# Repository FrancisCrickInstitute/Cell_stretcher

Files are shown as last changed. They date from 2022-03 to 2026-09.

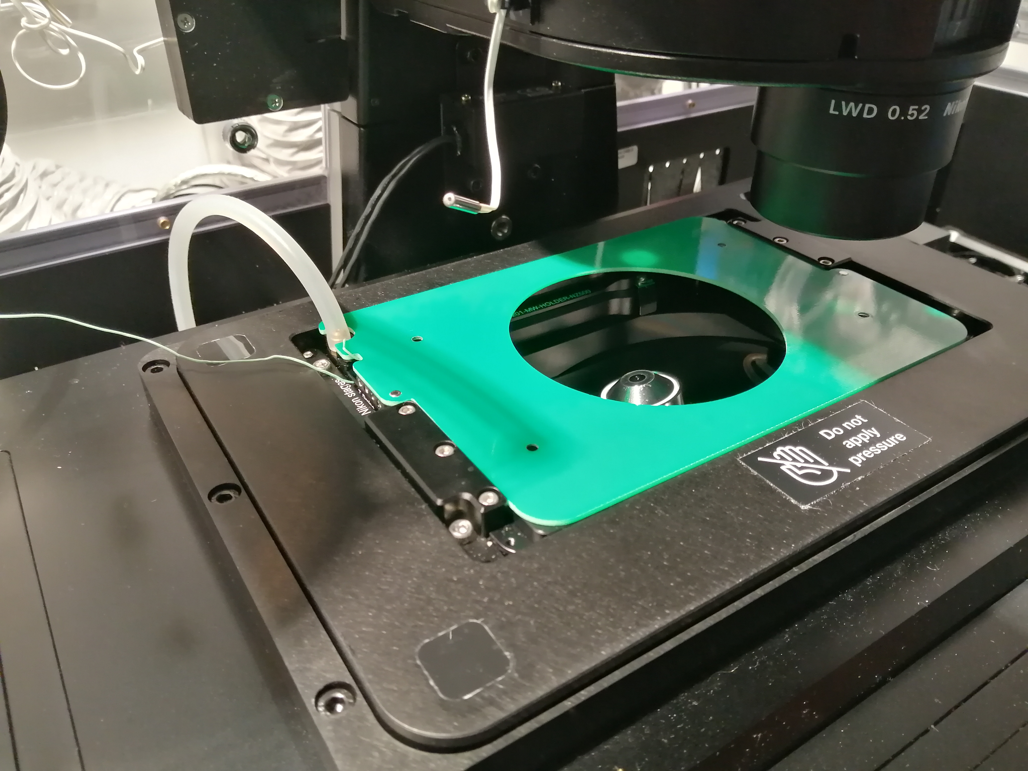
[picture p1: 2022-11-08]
IMG_20221101_121543.jpg

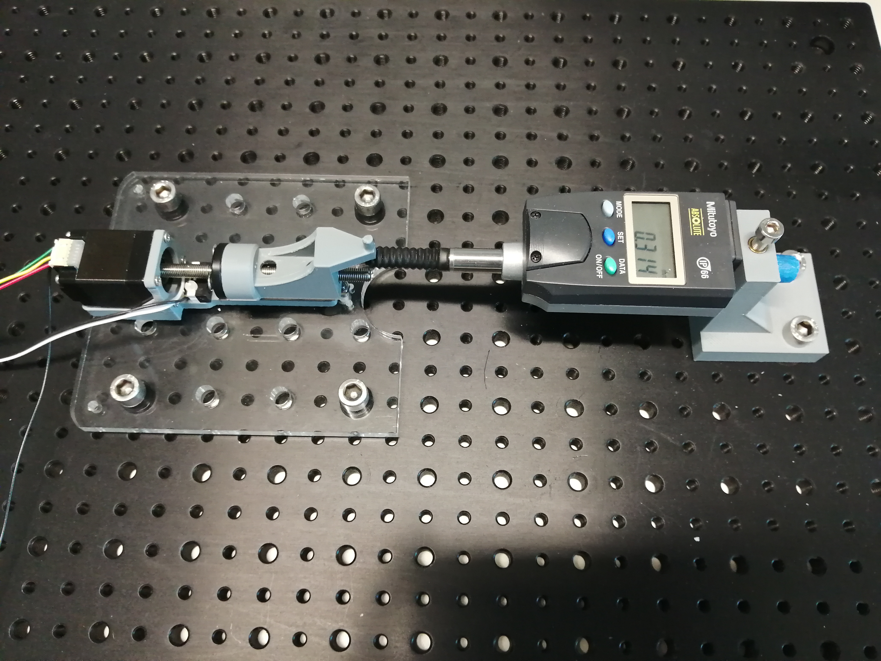
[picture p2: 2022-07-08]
IMG_20220622_173102.jpg

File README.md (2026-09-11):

### Cell sretcher 

Slide1



### Operation

-	Make sure the PDMS insert is not present!!
-	Connect power supply
-	Press ON/OFF button to ON position (| symbol)
-	The device will “home” all the actuators and move them to the centre
-	Load the PDMS insert
-	Select frequency (Hz)
-	Select stretch (mm)
-	Optional - Press stretch button to change mode (alternative, simultaneous…)
-	Press frequency button to start

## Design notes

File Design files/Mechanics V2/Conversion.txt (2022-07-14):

Conversion Report:

Created by DWG TrueView DWG Convert Monday, July 11, 2022, 1:57 PM.

Conversion Summary

------------------

Conversion File Format:  AutoCAD 2004/LT 2004 Drawing Format

Conversion package type: In-place (overwrite files)

Converted DWG files:     4

Recovered DWG files:     0

Conversion errors:       0

Converted Files

---------------

Root Drawings:

	C:\Users\ferrerx\Desktop\Projects\Microscope Calibration pattern\Drawing 1.dwg

	C:\Users\ferrerx\Desktop\Projects\Microscope Calibration pattern\1 circle.dwg

	C:\Users\ferrerx\Desktop\Projects\Microscope Calibration pattern\2 circle big.dwg

	C:\Users\ferrerx\Desktop\Projects\Microscope Calibration pattern\2 circle.dwg

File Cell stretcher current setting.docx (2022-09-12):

Cell stretcher current setting

VREF=8⋅IMAX⋅RCS

Red clone

VREF=8⋅0.6A⋅0.2Ω(Measured) =0.96V

Pololu original

VREF=8⋅0.6A⋅0.068Ω =0.326V

Reference: https://www.pololu.com/product/1182

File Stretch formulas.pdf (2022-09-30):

Stretcℎ (%) =

2 ∗ selected_stretcℎ(mm)
initial diameter(mm)

∗ 100

vel =

selected_stretcℎ(mm)
T
2

= 2

selected_stretcℎ(mm)
T

= 2fselected_stretcℎ(mm)

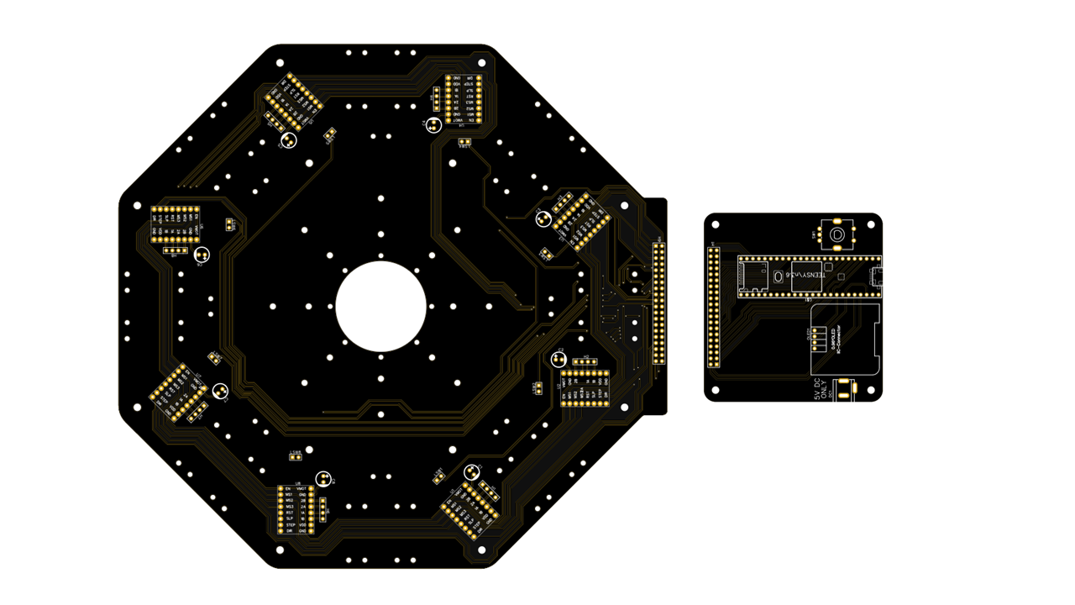
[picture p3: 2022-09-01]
Design files/Electronics/Cell stretcher board.png

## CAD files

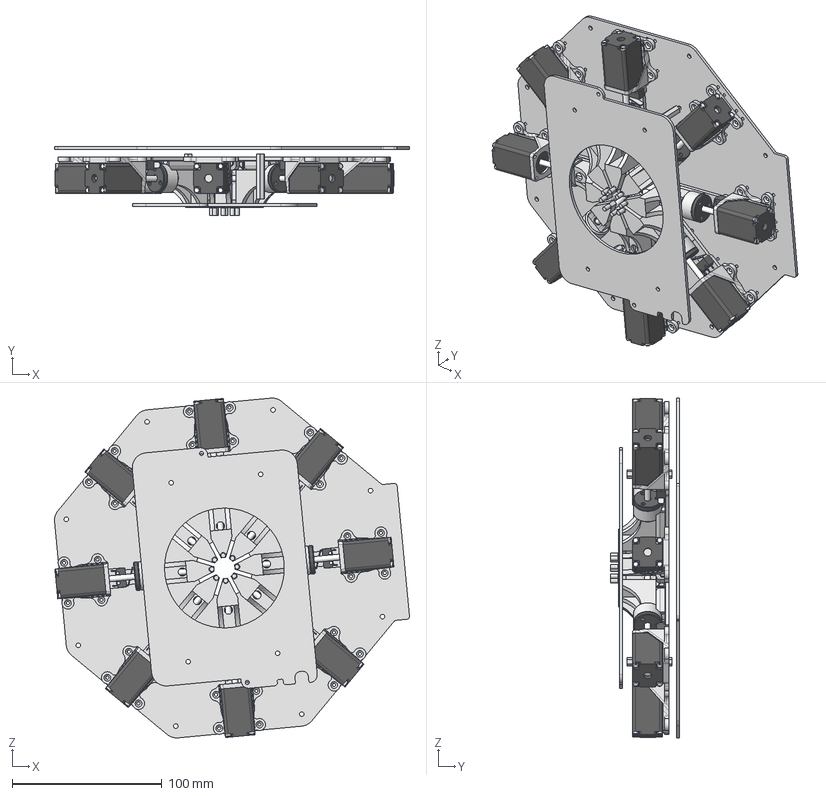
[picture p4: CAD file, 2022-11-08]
Design files/Mechanics/Cell stretcher assembly.stp
237.0 x 46.1 x 226.9 mm
Base
Motor holder x 8
Nema 8 x 8
Microswitch x 8
_BSP1025Rail x 8
_BSP-SL1025 Table x 8
_BSP1015.3 Retainer x 16
Nut x 8
Cart x 8
Microscope lid
Electronics spacer x 2

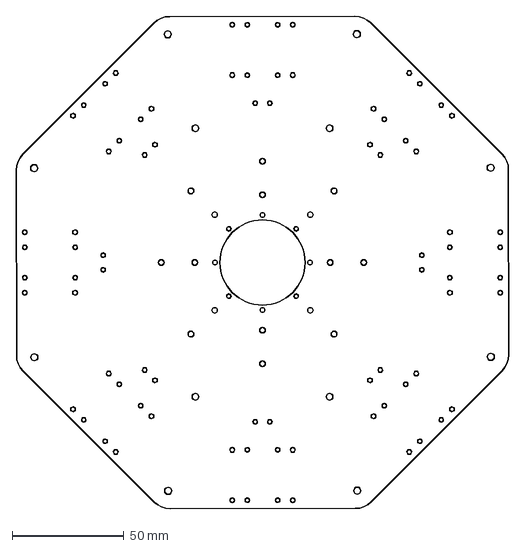
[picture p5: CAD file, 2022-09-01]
Design files/Electronics/Board_outline.dxf
220.1 x 220.1 mm

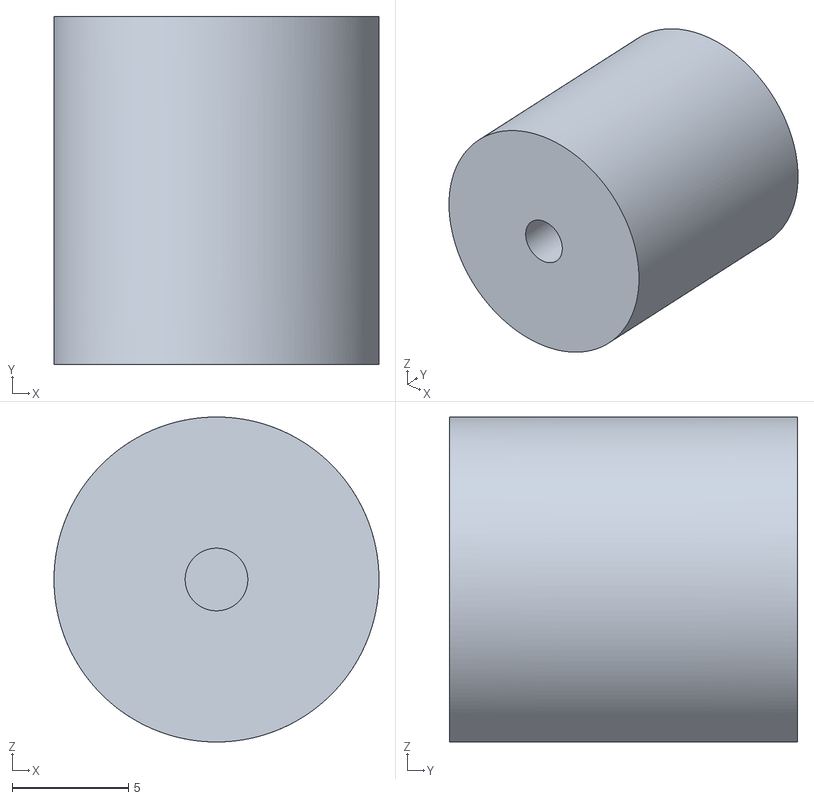
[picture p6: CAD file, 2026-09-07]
Four actuator mould/PDMS stretcher mould divided in parts_2.stl
14.0 x 15.0 x 14.0

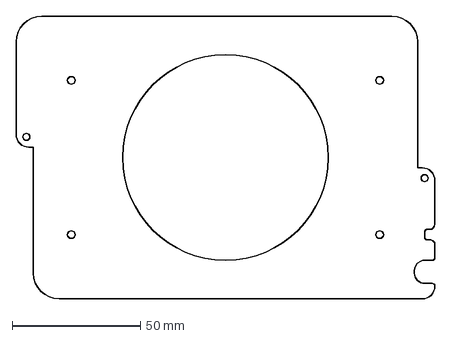
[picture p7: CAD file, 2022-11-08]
Manufacturing files/PCBs/Microscope lid.dxf
163.0 x 110.0 mm

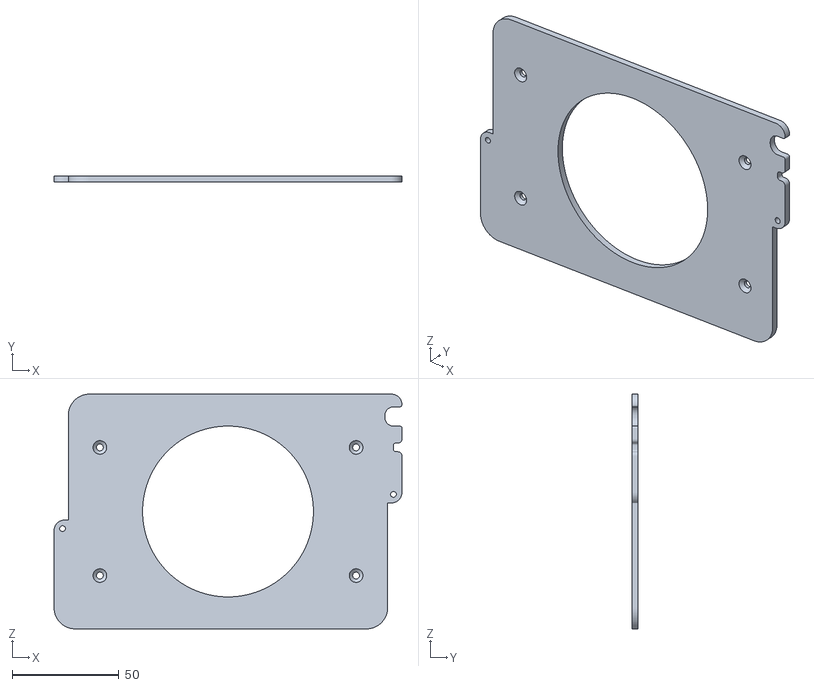
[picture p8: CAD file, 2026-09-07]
Manufacturing files/STL/Microscope lid.stl
163.0 x 3.00 x 110.0

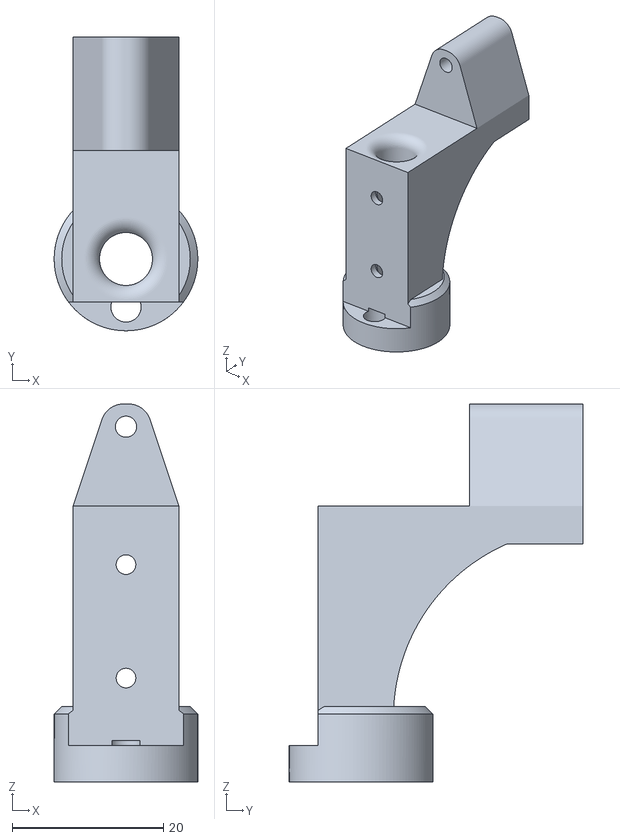
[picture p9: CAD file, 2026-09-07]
Manufacturing files/STL/V2/Cart.stl
19.0 x 38.8 x 50.0

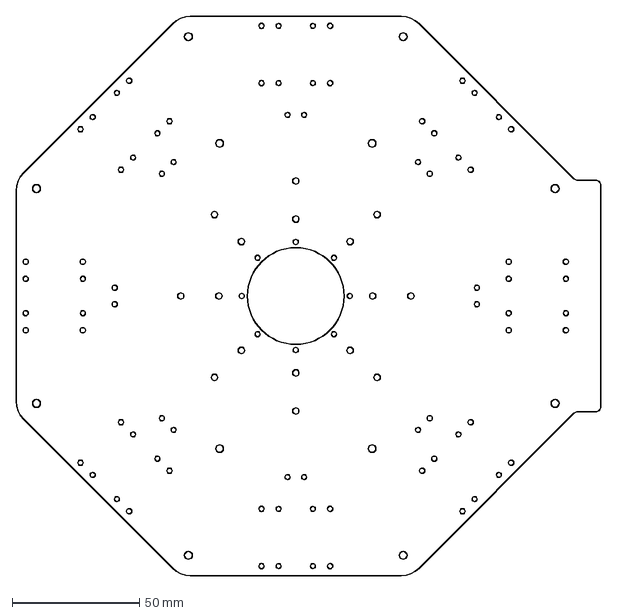
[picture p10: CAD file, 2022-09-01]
Design files/Mechanics/Cell stretcher Board.dxf
230.0 x 220.0 mm

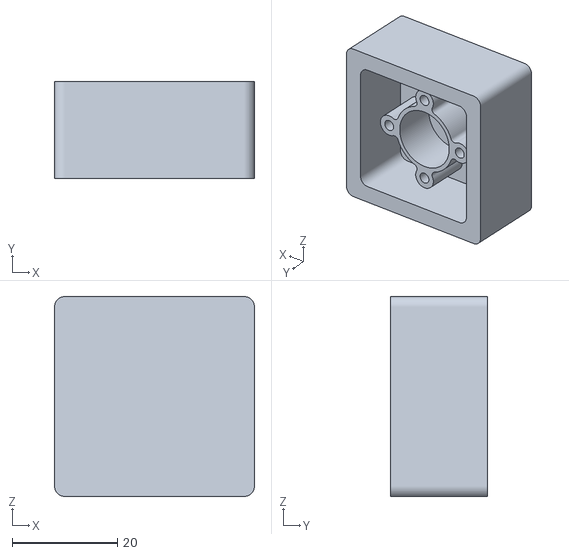
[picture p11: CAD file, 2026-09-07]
Four actuator mould/Ecoflex_mould_through.stl
38.0 x 18.5 x 38.0

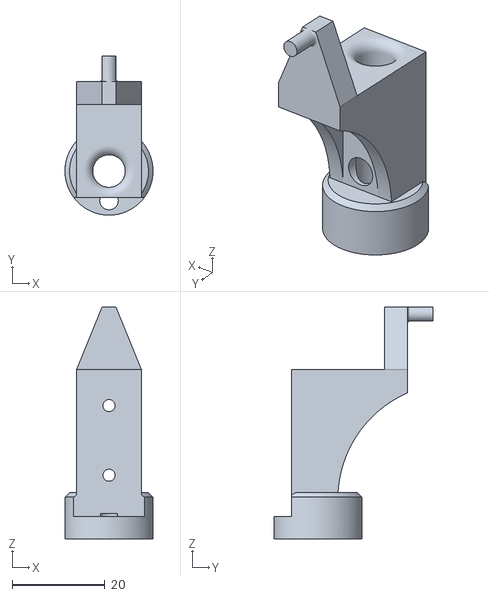
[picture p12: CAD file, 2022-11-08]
Manufacturing files/STL/Cart.stl
19.0 x 34.3 x 50.0

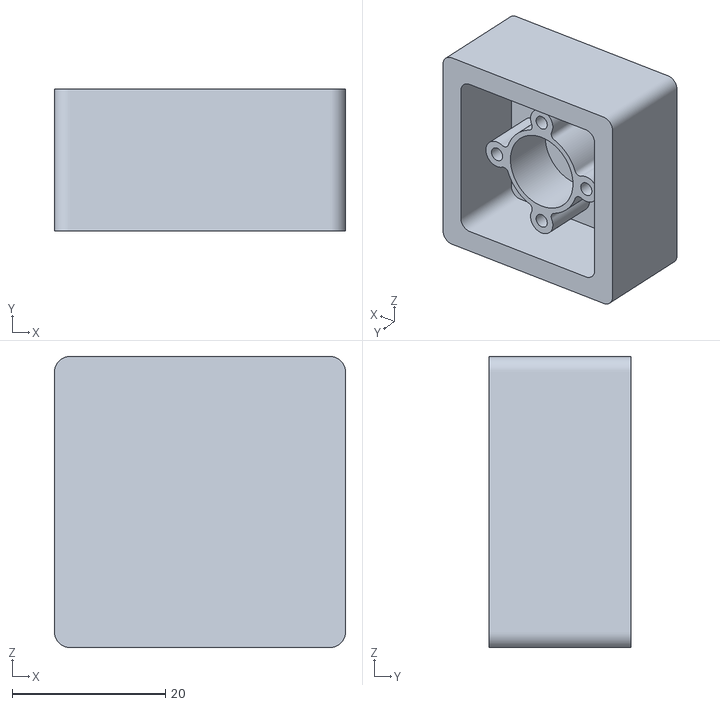
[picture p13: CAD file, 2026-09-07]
Four actuator mould/Ecoflex_mould.stl
38.0 x 18.5 x 38.0

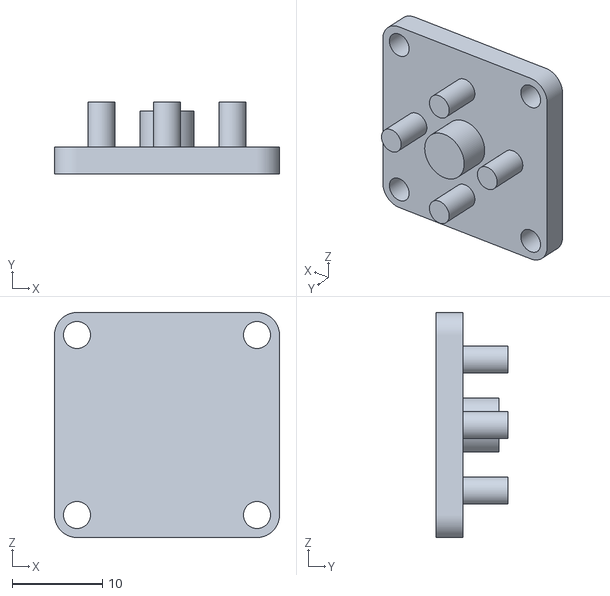
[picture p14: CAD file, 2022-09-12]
Four actuator mould/Manufacturing files/PDMS stretcher mould A (x4).stl
25.0 x 8.00 x 25.0

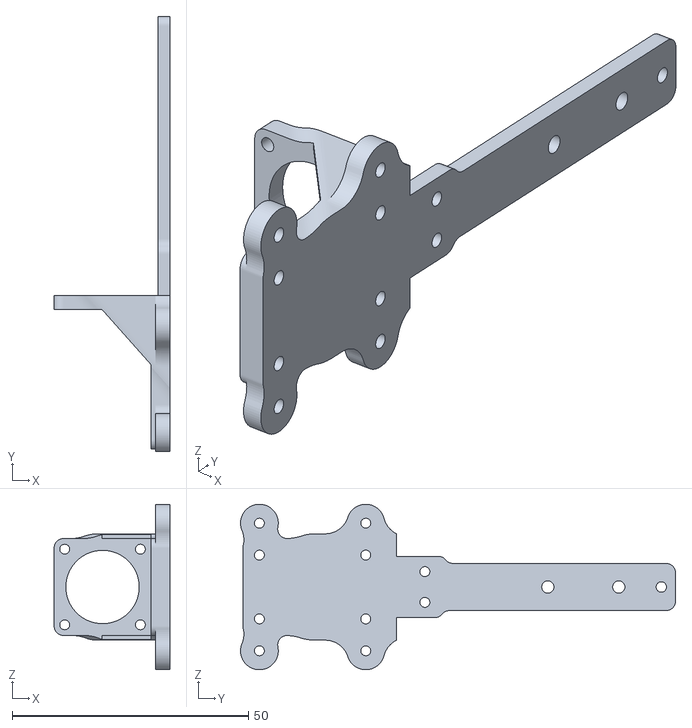
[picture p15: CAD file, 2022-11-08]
Manufacturing files/STL/Motor holder.stl
24.5 x 92.0 x 35.0

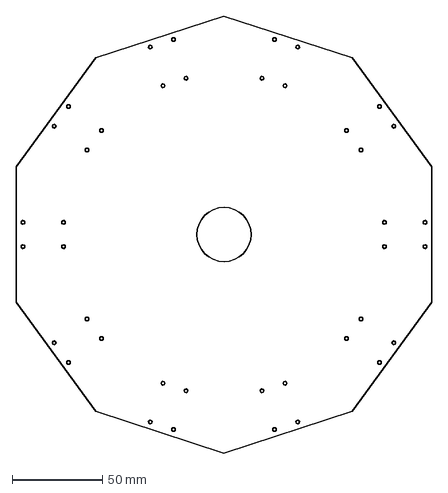
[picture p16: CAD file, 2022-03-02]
Design files/Mechanics/Base.dxf
230.0 x 241.8 mm

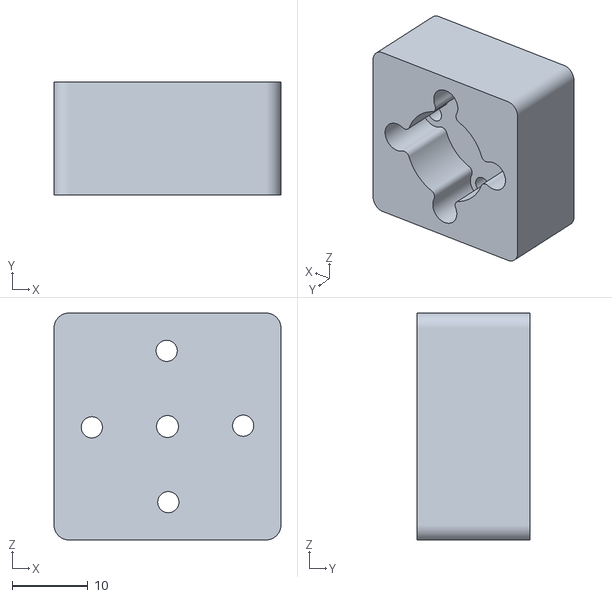
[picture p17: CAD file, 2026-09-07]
Four actuator mould/PDMS stretcher mould divided in parts.stl
30.0 x 15.0 x 30.0

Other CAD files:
Four actuator mould/Manufacturing files/Stretcher top mould x4.dwg
Four actuator mould/Manufacturing files/Stretcher intermediate mould x4.dwg
Design files/Mechanics/Top.dwg
Design files/Mechanics/BSP10-25.stp
Design files/Mechanics V2/BSP10-25 bottom.iam
Design files/Mechanics V2/BSP10-25 top.iam
Design files/Mechanics V2/BSP10-35 Top.iam
Design files/Mechanics V2/BSP10-35 bottom.iam
Design files/Mechanics V2/Base.ipt
Design files/Mechanics V2/Cart.ipt
Design files/Mechanics V2/Cell stretcher assembly.iam
Design files/Mechanics V2/Clamp.ipt
Design files/Mechanics V2/Coupler.ipt
Design files/Mechanics V2/Electronics spacer.ipt
Design files/Mechanics V2/Limit switch.ipt
Design files/Mechanics V2/Linear actuator.iam
Design files/Mechanics V2/M4 nut.ipt
Design files/Mechanics V2/M4 threaded bar.ipt
Design files/Mechanics V2/Microscope lid.ipt
Design files/Mechanics V2/Motor holder.ipt
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

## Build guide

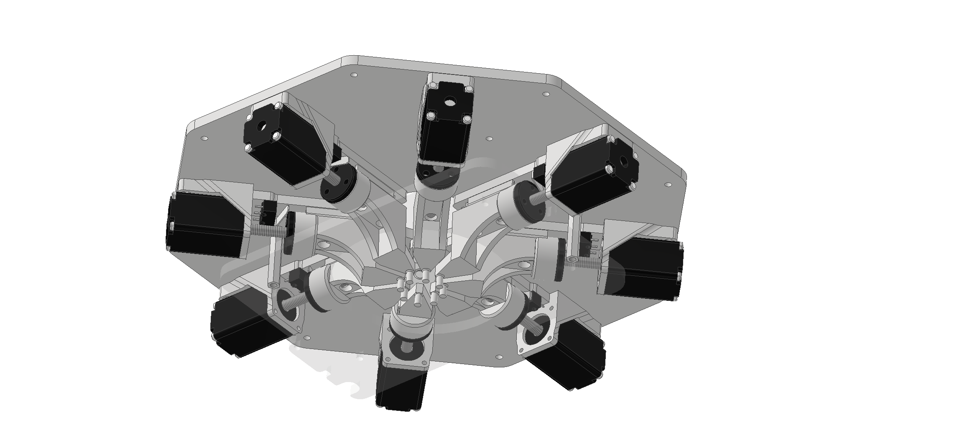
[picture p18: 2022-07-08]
Cell stretcher assembly.png

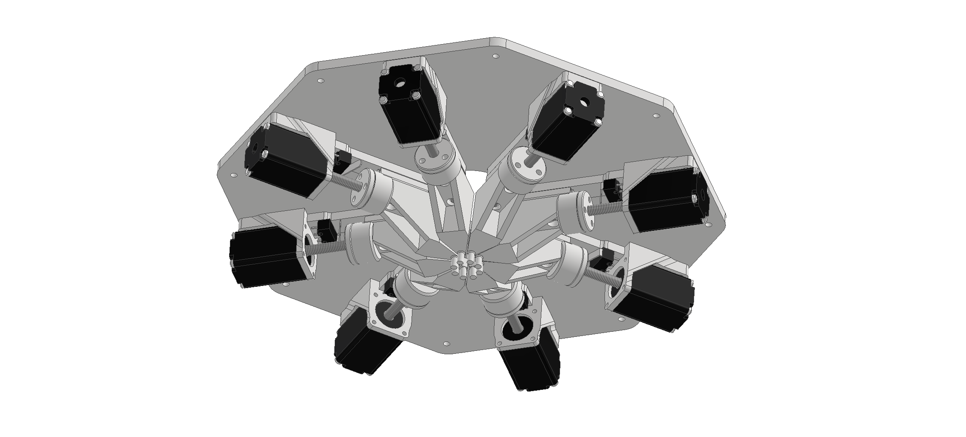
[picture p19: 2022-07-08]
Design files/Mechanics/Cell stretcher assembly.png

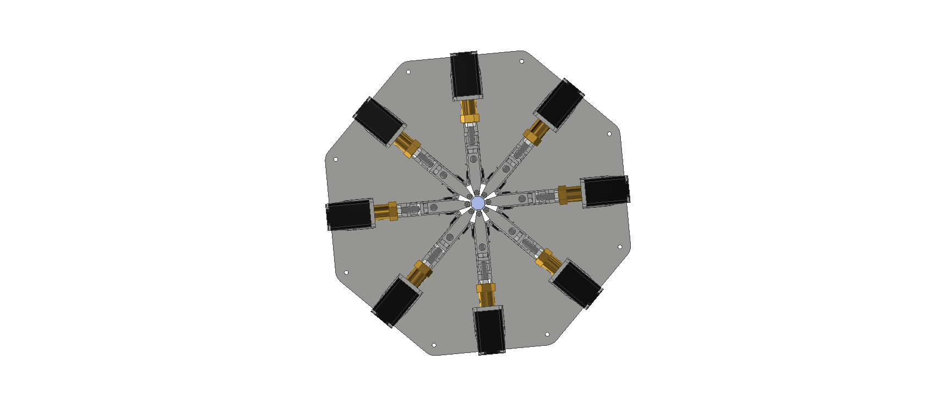
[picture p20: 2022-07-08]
Design files/Mechanics/Cell stretcher assembly top.png

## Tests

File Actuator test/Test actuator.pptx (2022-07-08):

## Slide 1

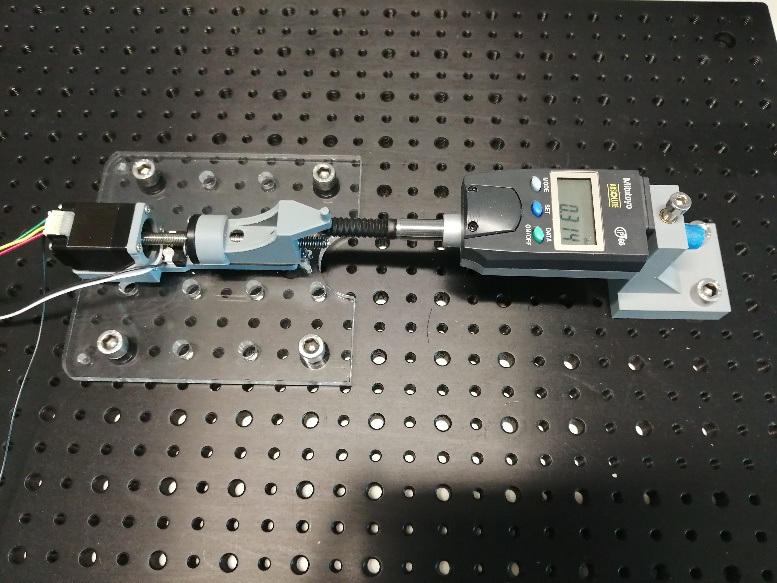
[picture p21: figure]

Resolution of 1.587 um ≈ 1.6 um

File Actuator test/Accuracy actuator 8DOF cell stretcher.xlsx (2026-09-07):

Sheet: Sheet3
Steps | um
0 | 2
10 | 17 | 15 | Average | 15.88461538
20 | 33 | 16
30 | 48 | 15
40 | 64 | 16
50 | 80 | 16
60 | 95 | 15
70 | 111 | 16
80 | 127 | 16
90 | 142 | 15
100 | 159 | 17
110 | 174 | 15
120 | 190 | 16
130 | 206 | 16
140 | 222 | 16
150 | 238 | 16
160 | 255 | 17
170 | 271 | 16
180 | 287 | 16
190 | 303 | 16
200 | 319 | 16
210 | 335 | 16
220 | 351 | 16
230 | 367 | 16
240 | 383 | 16
250 | 399 | 16
260 | 415 | 16

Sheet: Sheet2
1 revolution distance (400 steps)
1 |  | 2 |  | 3 |  | 4 |  | 5 |  | 6 |  | 7 |  | 8 |  | 9 |  | 10
316 | 0 | 318 | 0 | 315 | 0 | 315 | 0 | 314 | 0 | 314 | 0 | 314 | 0 | 312 | 0 | 313 | 0 | 313 | 0
941 | 625 | 945 | 627 | 943 | 628 | 943 | 628 | 945 | 631 | 945 | 631 | 945 | 631 | 943 | 631 | 944 | 631 | 945 | 632
1574 | 633 | 1578 | 633 | 1579 | 636 | 1578 | 635 | 1580 | 635 | 1580 | 635 | 1580 | 635 | 1579 | 636 | 1579 | 635 | 1580 | 635
2209 | 635 | 2213 | 635 | 2214 | 635 | 2214 | 636 | 2215 | 635 | 2215 | 635 | 2216 | 636 | 2214 | 635 | 2215 | 636 | 2215 | 635
 |  | 1 |  | 2 |  | 3 |  | 4 |  | 5 |  | 6 |  | 7 |  | 8 |  | 9 |  | 10
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

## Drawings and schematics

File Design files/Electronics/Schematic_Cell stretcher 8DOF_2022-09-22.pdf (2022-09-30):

## Servo motor drivers

## Homing limit switches

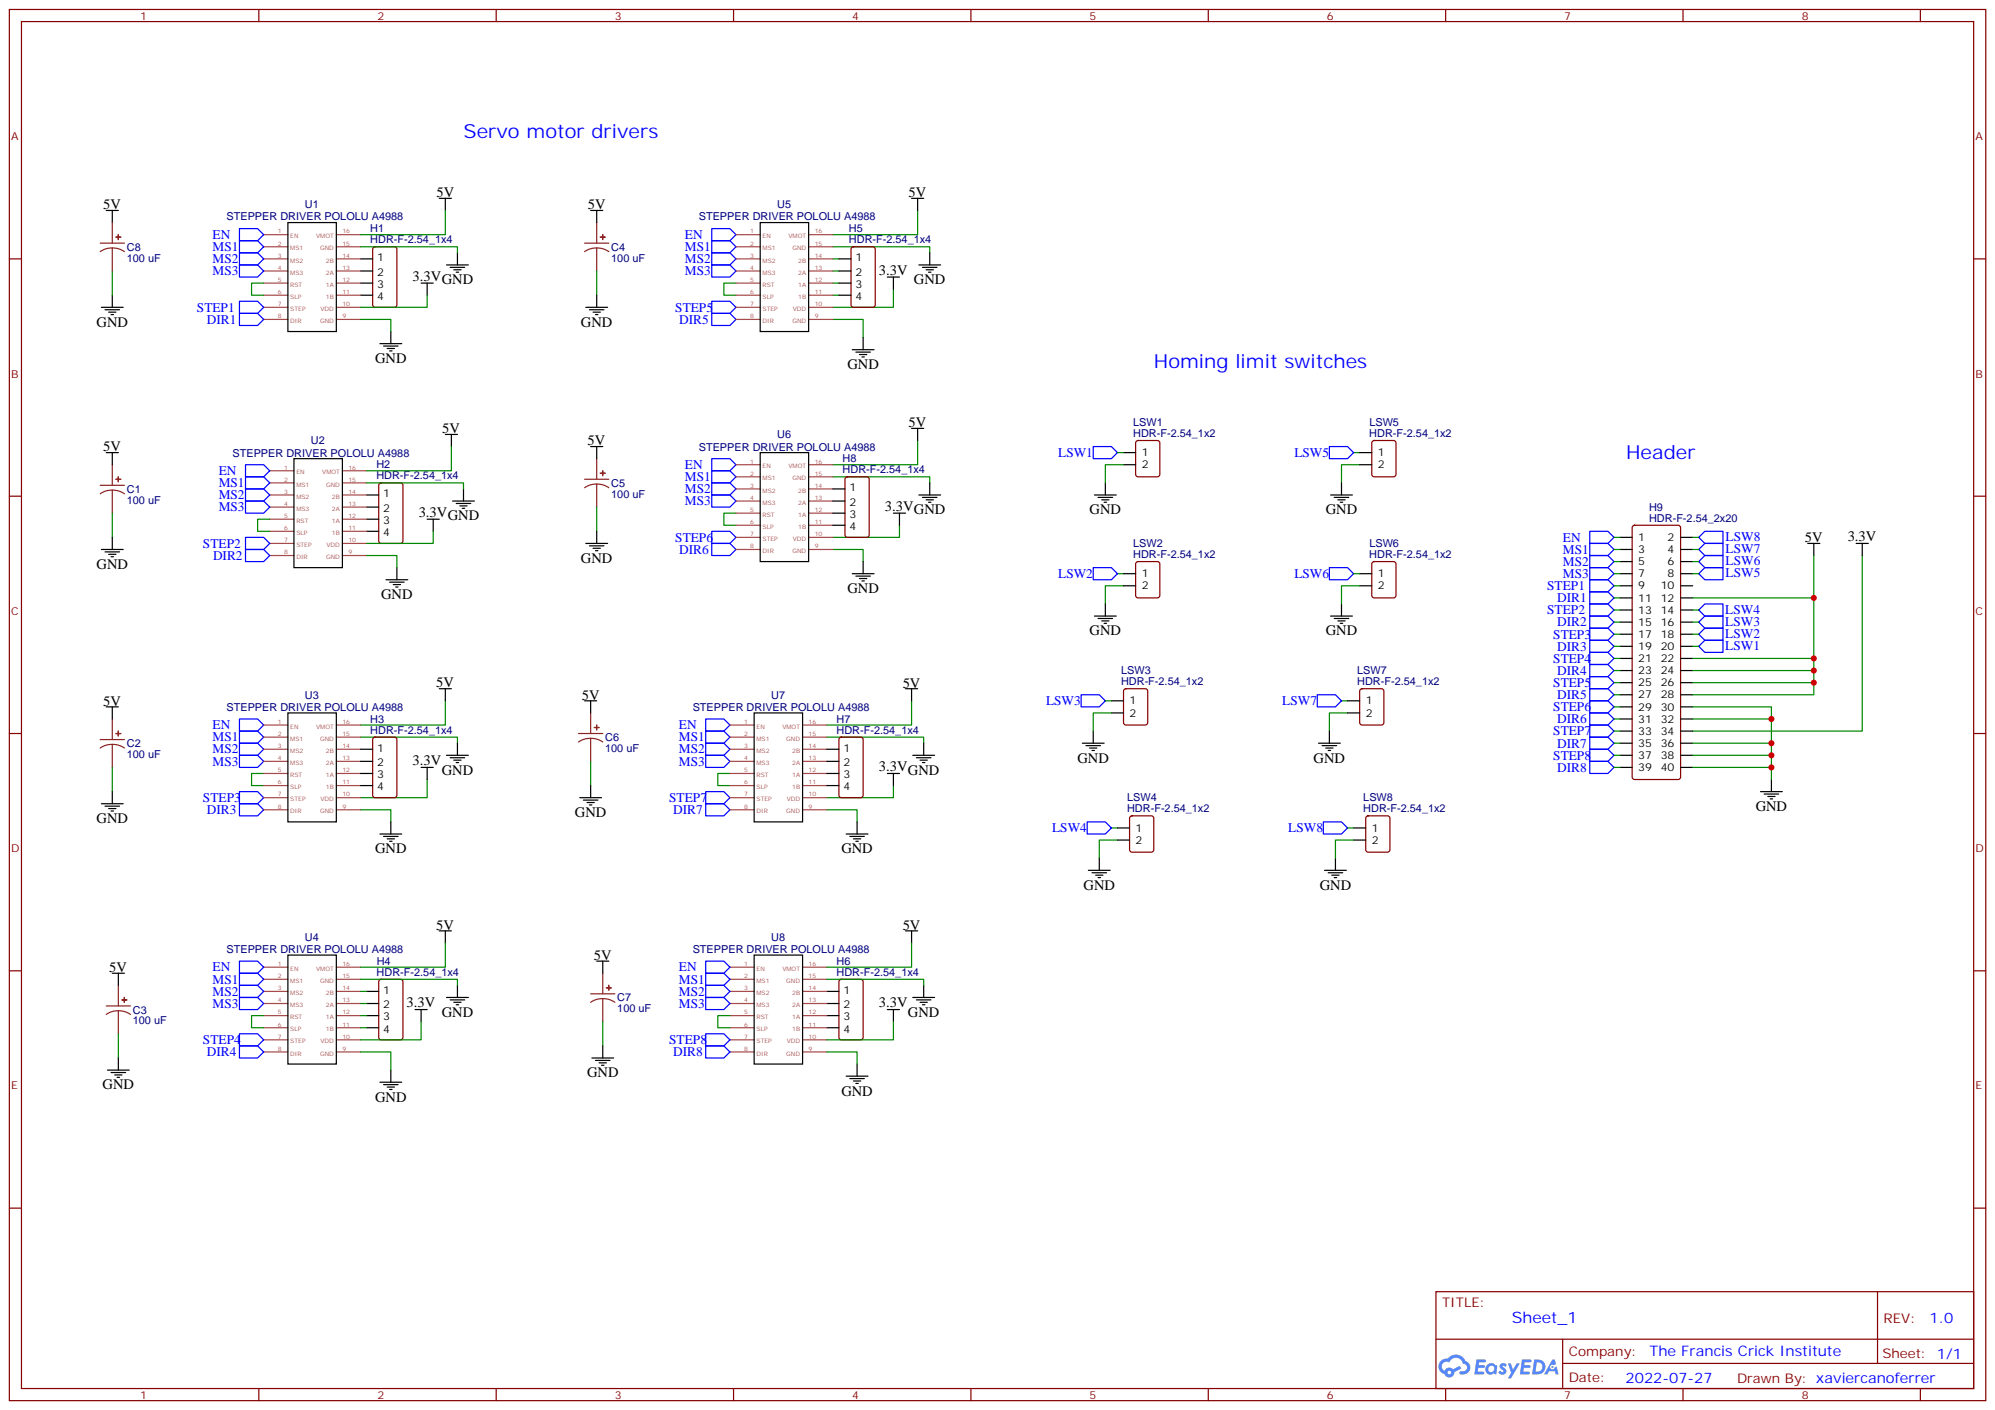
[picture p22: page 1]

Company: The Francis Crick Institute

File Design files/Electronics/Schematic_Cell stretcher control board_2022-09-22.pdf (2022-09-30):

## Teensy 3.5 Power

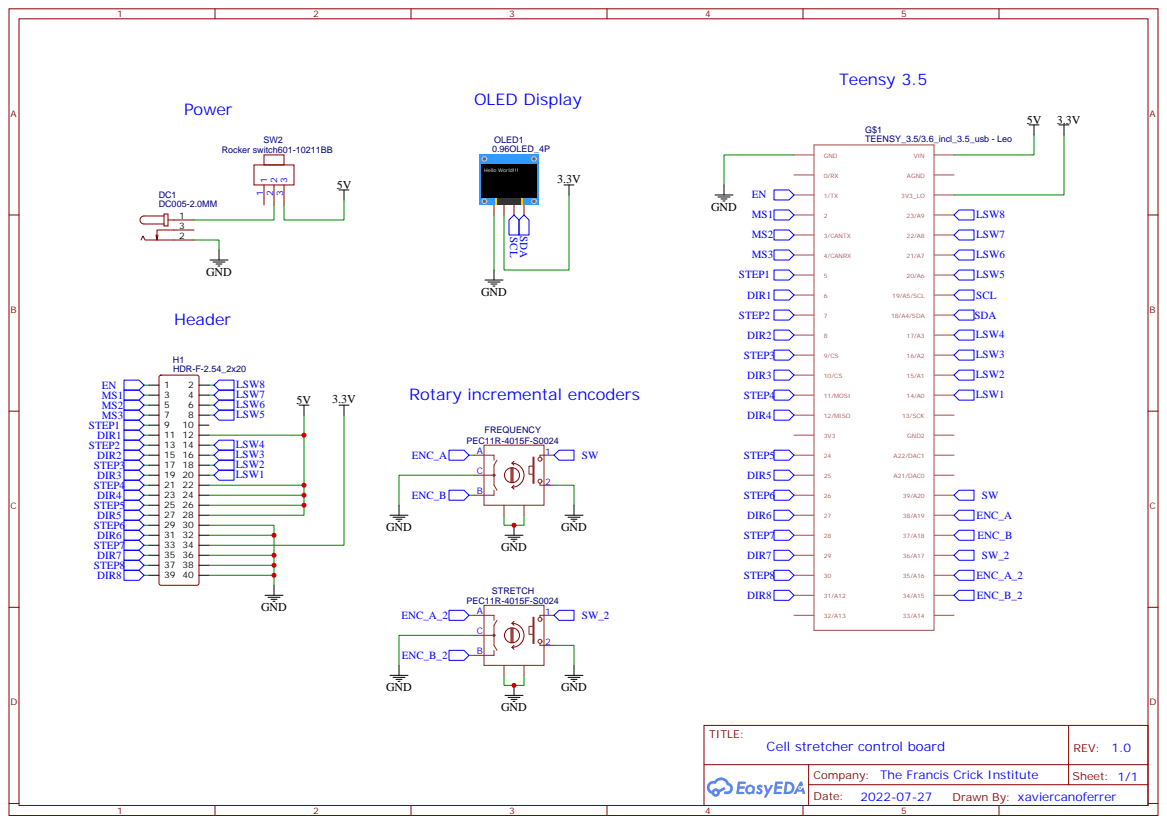
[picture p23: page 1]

Company: The Francis Crick Institute

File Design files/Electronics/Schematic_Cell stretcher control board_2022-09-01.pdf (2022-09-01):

## Teensy 3.5 Power

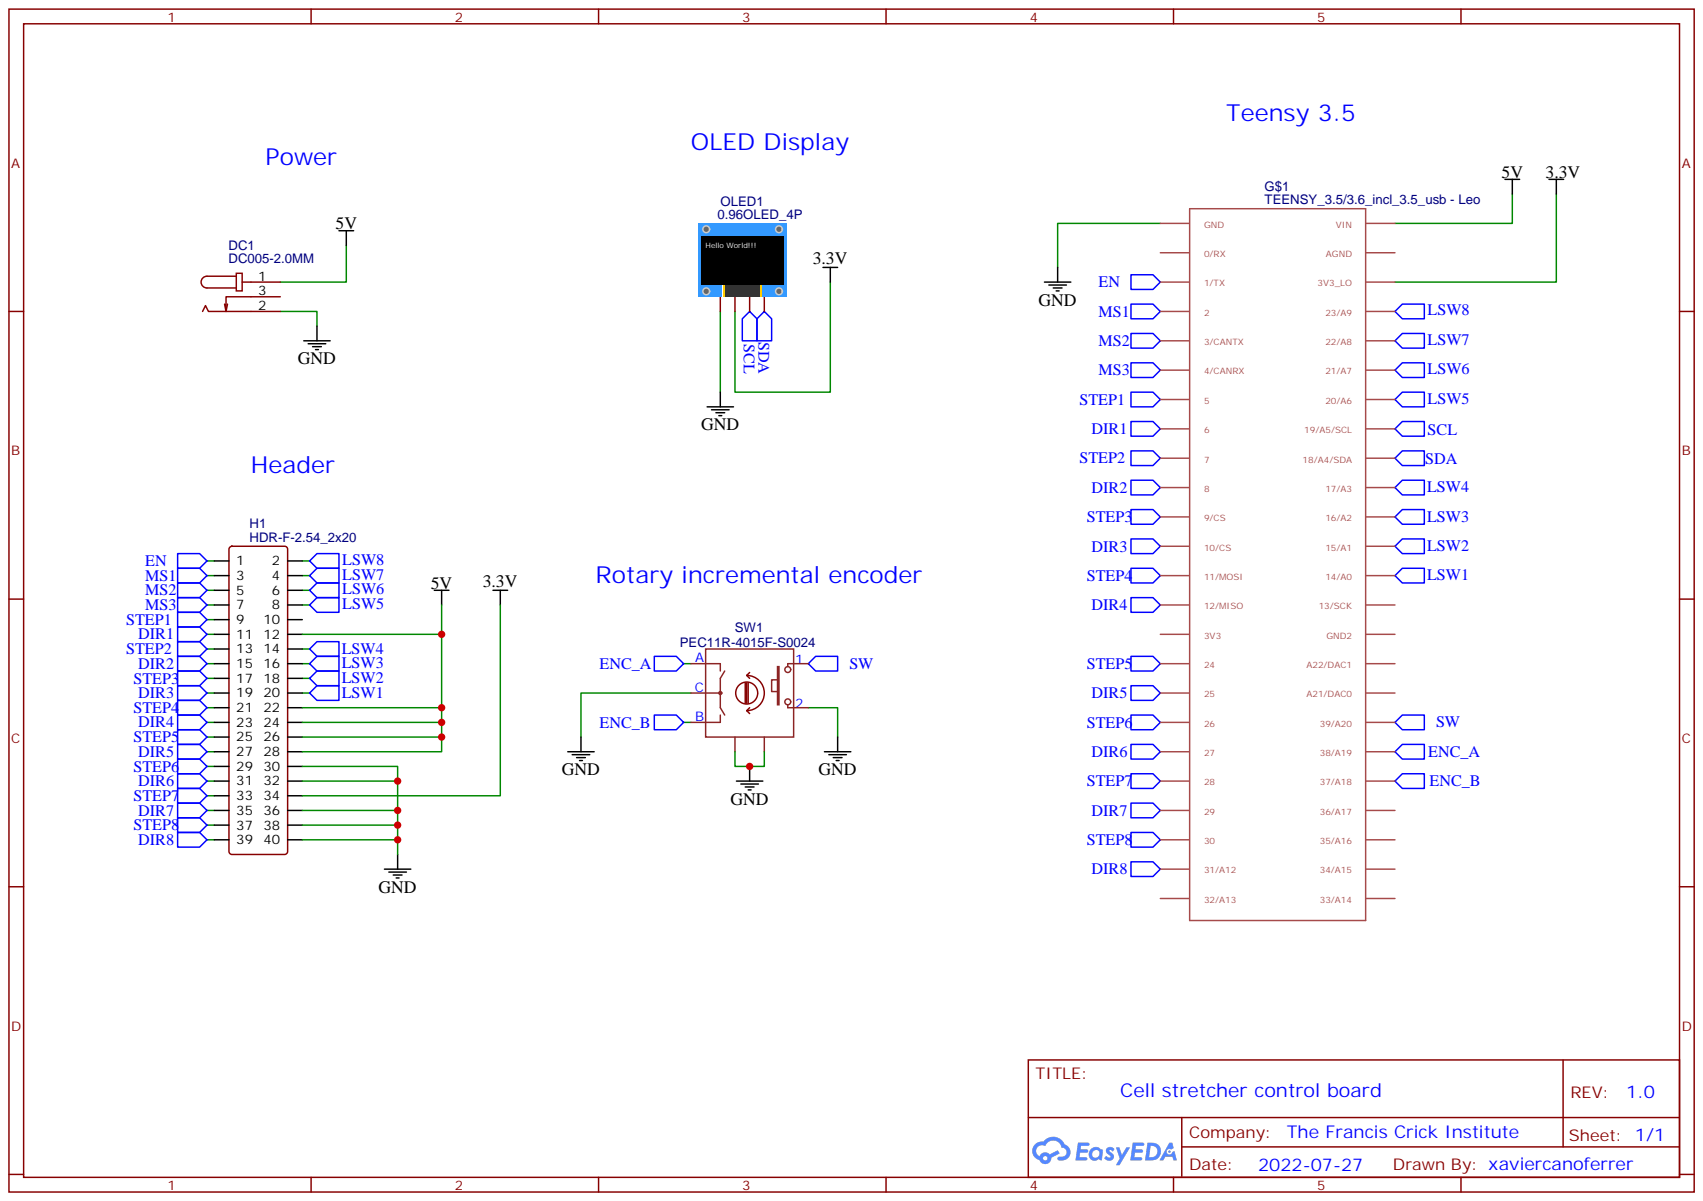
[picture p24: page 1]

Company: The Francis Crick Institute

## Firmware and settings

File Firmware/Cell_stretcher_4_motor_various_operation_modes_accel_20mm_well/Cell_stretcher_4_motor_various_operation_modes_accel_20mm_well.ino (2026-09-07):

#include "TeensyStep.h"
#include <Encoder.h>
#include <Wire.h>
#include <Adafruit_GFX.h>
#include <Adafruit_SSD1306.h>
#include <Bounce.h>

Encoder freq_knob(38, 37);
Encoder stretch_knob(35, 34);


const int encoder_SW = 39;
const int encoder_SW_2 = 36;

// Instantiate a Bounce object with a 5 millisecond debounce time
Bounce pushbutton = Bounce( encoder_SW,20 ); 
Bounce pushbutton2 = Bounce( encoder_SW_2,20 ); 

const int Enable = 1;

Stepper M1(7, 8);       // STEP pin: 7, DIR pin: 6  // The stepper class encapsulates the physical properties of a stepper motor like pin numbers of the STEP and DIR signals, speed and acceleration of the motor.
Stepper M2(11, 12);
Stepper M3(26, 27);
Stepper M4(30, 31);

const int SW1 = 15;
const int SW2 = 17;
const int SW3 = 21;
const int SW4 = 23;

StepControl step_controller;    // The StepControl class is used to synchronously move up to 10 motors to their target positions.

#define SCREEN_WIDTH 128 // OLED display width, in pixels
#define SCREEN_HEIGHT 64 // OLED display height, in pixels

// Declaration for an SSD1306 display connected to I2C (SDA, SCL pins)
#define OLED_RESET     -1 // Reset pin # (or -1 if sharing Arduino reset pin)

Adafruit_SSD1306 display(SCREEN_WIDTH, SCREEN_HEIGHT, &Wire, OLED_RESET);

const int MS1 = 2;
const int MS2 = 3;
const int MS3 = 4;

float um_per_step = 1.6; //400 steps/revolution
int steps = 0;
const int initial_steps = 3000-1080;//3000;
const int compression_steps = 3000;

int mode = 0;

float freq = 0;
float freq_factor = 0.05;
float stretch = 0;
float T;
const float initial_stretch_diameter = 20;
float p_stretch;
unsigned long t = 0;
bool state = 0;
float vel;
int steps_s;
float accel;
int steps_s2;

void setup()
{
  pinMode(MS1, OUTPUT);    // set the MS1, MS2, MS3 and Enable as an outputs
  pinMode(MS2, OUTPUT);
  pinMode(MS3, OUTPUT);

  pinMode(Enable, OUTPUT);

  digitalWrite(MS1, HIGH); // sets the digital pin MS1, MS2, MS3 to HIGH
  digitalWrite(MS2, LOW);
  digitalWrite(MS3, LOW);

  digitalWrite(Enable, LOW); // set the enables to LOW

  // Set the motor max acceleration
  M1.setMaxSpeed(1000)
  .setAcceleration(5000)   // stp/s^2
  .setInverseRotation(true);

  M2.setMaxSpeed(1000)
  .setAcceleration(5000)   // stp/s^2
  .setInverseRotation(true);

  M3.setMaxSpeed(1000)
  .setAcceleration(5000)   // stp/s^2
  .setInverseRotation(true);

  M4.setMaxSpeed(1000)
  .setAcceleration(5000)   // stp/s^2
  .setInverseRotation(true);

  pinMode(SW1, INPUT_PULLUP);
  pinMode(SW2, INPUT_PULLUP);
  pinMode(SW3, INPUT_PULLUP);
  pinMode(SW4, INPUT_PULLUP);
  
  pinMode(encoder_SW, INPUT_PULLUP);
  pinMode(encoder_SW_2, INPUT_PULLUP);
  
  Serial.begin(115200);

  display.begin(SSD1306_SWITCHCAPVCC, 0x3C);

  delay(1000);
  display.clearDisplay(); 

  Homing_routine();

  // Go to initial position
  M1.setTargetAbs(initial_steps);
  M2.setTargetAbs(initial_steps);
  M3.setTargetAbs(initial_steps);
  M4.setTargetAbs(initial_steps);
  step_controller.move(M1, M2, M3, M4);

  
  digitalWrite(Enable, HIGH); // Remove power from the motor to decrease heat
}

void loop()
{

  freq = abs(freq_knob.read())/4*freq_factor; // Select the frequency in Hz
  stretch = abs(stretch_knob.read())/4*0.05; // select the stretch in mm 

  //Constrained frequancy and stretch
  freq = constrain(freq, 0, 4);
  stretch = constrain(stretch, 0, 2);
  
  // Calculate percentage of stretch, period and motor speed based on the previous user selection
  p_stretch = 2*stretch/(initial_stretch_diameter)*100; //2 times because it is in 2 directions simultaneously
  T = 1/freq; // Calculate the period
  
  vel = 1.5*(stretch/(T/2)); // 1.5 = 3/2 Because 1/3 of the time is used for accelerating, 1/3 is used for constant velocity, and 1/3 is used for decelerating.
  accel = vel/(T/6);
  
  //t = T*1000; // Convert the period in milliseconds

  // Get steps from mm selected by the user using the stretch knob
  steps = mm_to_step(stretch/2); // Divided by two beacuse it is what will move each arm

  // Get steps/s from the selected velocity
  steps_s = mm_to_step(vel);

  // Get steps/s^2 from the acceleration calculated based on displacement and frequency
  steps_s2 = mm_to_step(accel);
  
  //Set the selected motor speed
  set_velocity(steps_s);

  //Set the acceleration
  set_acceleration(steps_s2);

  OLED_display(); // Display selection

  read_pushbutton();
  read_pushbutton2();

  if (state == 1 && mode == 0)
  {
    read_pushbutton();
    simultaneous();  
  }

  if (state == 1 && mode == 1)
  {
    read_pushbutton();
    alternate();  
  }
  if (state == 1 && mode == 2)
  {
    read_pushbutton();
    one_by_one();
  };
  if (state == 1 && mode == 3)
  {
    read_pushbutton();
    x_axis();
  };
  if (state == 1 && mode == 4)
  {
    read_pushbutton();
    y_axis();
  };
  if (state == 1 && mode == 5)
  {
    read_pushbutton();
    compression();
  };
}

// Function to get the steps from the mm
int mm_to_step (float mm)
{
  int steps;
  steps = mm * 1600; // 1600 steps per mm
  return steps;
}

// Function to get the mm from the steps
float step_to_mm (int steps)
{
  float mm;
  mm = steps * 0.001600; // 1.587 um per step
  return mm;
}

//Function to rotate the left motor CW
void TurnClockwise_M1 (int pd)
{
  digitalWrite(8, 1);
  digitalWrite(7, HIGH);
  digitalWrite(7, LOW);
  delayMicroseconds(pd);
}

//Function to rotate the right motor CW
void TurnClockwise_M2 (int pd)
{
  digitalWrite(12, 1);
  digitalWrite(11, HIGH);
  digitalWrite(11, LOW);
  delayMicroseconds(pd);
}

void TurnClockwise_M3 (int pd)
{
  digitalWrite(27, 1);
  digitalWrite(26, HIGH);
  digitalWrite(26, LOW);
  delayMicroseconds(pd);
}

void TurnClockwise_M4 (int pd)
{
  digitalWrite(31, 1);
  digitalWrite(30, HIGH);
  digitalWrite(30, LOW);
  delayMicroseconds(pd);
}


void read_pushbutton()
{
  if (pushbutton.update())
  {
    if (pushbutton.fallingEdge())
    {
      state = !state;
    }
  }
}

void read_pushbutton2()
{
  if (pushbutton2.update())
  {
    if (pushbutton2.fallingEdge())
    {
      mode = mode +1;
      mode = constrain(mode, 0, 5);
    }
  }
}

void Homing_routine()
{
  
  while (digitalRead(SW1) == HIGH)
  {
    TurnClockwise_M1 (1000);
    Serial.println(digitalRead(SW1));
  }

  while (digitalRead(SW2) == HIGH)
  {
    TurnClockwise_M2 (1000);
    Serial.println(digitalRead(SW2));
  }

  while (digitalRead(SW3) == HIGH)
  {
    TurnClockwise_M3 (1000);
    Serial.println(digitalRead(SW3));
  }

  while (digitalRead(SW4) == HIGH)
  {
    TurnClockwise_M4 (1000);
    Serial.println(digitalRead(SW4));
  }
}

void set_velocity(int v)
{  
  // Set the motor max speed
  M1.setMaxSpeed(v);
  M2.setMaxSpeed(v);
  M3.setMaxSpeed(v);
  M4.setMaxSpeed(v);
}

void set_acceleration(int a)
{  
  // Set the motor max speed
  M1.setAcceleration(a);
  M2.setAcceleration(a);
  M3.setAcceleration(a);
  M4.setAcceleration(a);
}
void OLED_display()
{
  display.clearDisplay();
  display.setTextColor(WHITE);        // Draw white text
  display.setCursor(0, 0);
  display.setTextSize(1);
  display.println(F("8 DOF cell stretcher"));
  display.println();
  display.print(F("Frequency:"));
  display.print(freq);
  display.println(F(" Hz"));
  //display.println();
  display.print(F("Stretch:"));
  display.print(stretch);
  display.println(F(" mm"));
  //display.println();
  display.print(F("%Stretch:"));
  display.print(p_stretch);
  display.println(F(" %"));
//  display.print(F("Steps stretch:"));
//  display.println(steps);
  //display.println();
  display.print(F("Period:"));
  display.print(T);
  display.println(F(" s"));
  //display.println();
  display.print(F("State:"));
  //display.print(state);
  if (state == 0){display.println(F("Inactive"));}
  if (state == 1){display.println(F("Active"));}
  display.print(F("Mode:"));
  if (mode == 0){display.println(F("Simult"));}
  if (mode == 1){display.println(F("Alternate"));}
  if (mode == 2){display.println(F("Separete"));}
  if (mode == 3){display.println(F("X axis"));}
  if (mode == 4){display.println(F("Y axis"));}
  if (mode == 5){display.println(F("Compress"));}
  display.print(mode);
  display.display();
}

void simultaneous()
{
   digitalWrite(Enable, LOW); // Enable the motor again
    
    // Set the target for each motor and move to the target
    M1.setTargetAbs(initial_steps-steps);
    M2.setTargetAbs(initial_steps-steps);
    M3.setTargetAbs(initial_steps-steps);
    M4.setTargetAbs(initial_steps-steps);
    step_controller.move(M1, M2, M3, M4);

    digitalWrite(Enable, HIGH); // Remove power from the motor to decrease heat

    //delay(t);

    digitalWrite(Enable, LOW); // Enable the motor again

    // Com back to the origin
    M1.setTargetAbs(initial_steps);
    M2.setTargetAbs(initial_steps);
    M3.setTargetAbs(initial_steps);
    M4.setTargetAbs(initial_steps);
    step_controller.move(M1, M2, M3, M4);

    digitalWrite(Enable, HIGH); // Remove power from the motor to decrease heat  
}


void compression()
{
   digitalWrite(Enable, LOW); // Enable the motor again
    
    // Set the target for each motor and move to the target
    M1.setTargetAbs(initial_steps-steps);
    M2.setTargetAbs(initial_steps-steps);
    M3.setTargetAbs(initial_steps-steps);
    M4.setTargetAbs(initial_steps-steps);
    step_controller.move(M1, M2, M3, M4);

    digitalWrite(Enable, HIGH); // Remove power from the motor to decrease heat

    //delay(t);

    digitalWrite(Enable, LOW); // Enable the motor again

    // Com back to the origin but 2 mm closer
    M1.setTargetAbs(compression_steps);
    M2.setTargetAbs(compression_steps);
    M3.setTargetAbs(compression_steps);
    M4.setTargetAbs(compression_steps);
    step_controller.move(M1, M2, M3, M4);

    digitalWrite(Enable, HIGH); // Remove power from the motor to decrease heat  
}

void alternate()
{
    
    digitalWrite(Enable, LOW); // Enable the motor again
    
    // Move x axis
    M1.setTargetAbs(initial_steps-steps);
    M3.setTargetAbs(initial_steps-steps);
    step_controller.move(M1, M3);

    digitalWrite(Enable, HIGH); // Remove power from the motor to decrease heat

    //delay(t);

    digitalWrite(Enable, LOW); // Enable the motor again

    // Com back to the origin
    M1.setTargetAbs(initial_steps);
    M3.setTargetAbs(initial_steps);
    step_controller.move(M1, M3);

    digitalWrite(Enable, HIGH); // Remove power from the motor to decrease heat  

    digitalWrite(Enable, LOW); // Enable the motor again

    // Move y axis
    M2.setTargetAbs(initial_steps-steps);
    M4.setTargetAbs(initial_steps-steps);
    step_controller.move(M2, M4);

    digitalWrite(Enable, HIGH); // Remove power from the motor to decrease heat

    //delay(t);

    digitalWrite(Enable, LOW); // Enable the motor again

    // Com back to the origin
    M2.setTargetAbs(initial_steps);
    M4.setTargetAbs(initial_steps);
    step_controller.move(M2, M4);

    digitalWrite(Enable, HIGH); // Remove power from the motor to decrease heat  
}

void one_by_one()
{
    
   digitalWrite(Enable, LOW); // Enable the motor again
    
    // Set the target for each motor and move to the target
    M1.setTargetAbs(initial_steps-steps);
    step_controller.move(M1);

    digitalWrite(Enable, HIGH); // Remove power from the motor to decrease heat

    //delay(t);

    digitalWrite(Enable, LOW); // Enable the motor again

    // Com back to the origin
    M1.setTargetAbs(initial_steps);
    step_controller.move(M1);

    digitalWrite(Enable, HIGH); // Remove power from the motor to decrease heat  

    digitalWrite(Enable, LOW); // Enable the motor again
    
    // Set the target for each motor and move to the target
    M2.setTargetAbs(initial_steps-steps);
    step_controller.move(M2);

    digitalWrite(Enable, HIGH); // Remove power from the motor to decrease heat

    //delay(t);

    digitalWrite(Enable, LOW); // Enable the motor again

    // Com back to the origin
    M2.setTargetAbs(initial_steps);
    step_controller.move(M2);

    digitalWrite(Enable, HIGH); // Remove power from the motor to decrease heat  


    digitalWrite(Enable, LOW); // Enable the motor again
    
    // Set the target for each motor and move to the target
    M3.setTargetAbs(initial_steps-steps);
    step_controller.move(M3);

    digitalWrite(Enable, HIGH); // Remove power from the motor to decrease heat

    //delay(t);

    digitalWrite(Enable, LOW); // Enable the motor again

    // Com back to the origin
    M3.setTargetAbs(initial_steps);
    step_controller.move(M3);

    digitalWrite(Enable, HIGH); // Remove power from the motor to decrease heat 



    digitalWrite(Enable, LOW); // Enable the motor again
    
    // Set the target for each motor and move to the target
    M4.setTargetAbs(initial_steps-steps);
    step_controller.move(M4);

    digitalWrite(Enable, HIGH); // Remove power from the motor to decrease heat

    //delay(t);

    digitalWrite(Enable, LOW); // Enable the motor again

    // Com back to the origin
    M4.setTargetAbs(initial_steps);
    step_controller.move(M4);

    digitalWrite(Enable, HIGH); // Remove power from the motor to decrease heat 
}

void y_axis()
{
    
    digitalWrite(Enable, LOW); // Enable the motor again
    
    // Move x axis
    M1.setTargetAbs(initial_steps-steps);
    M3.setTargetAbs(initial_steps-steps);
    step_controller.move(M1, M3);

    digitalWrite(Enable, HIGH); // Remove power from the motor to decrease heat

    //delay(t);

    digitalWrite(Enable, LOW); // Enable the motor again

    // Com back to the origin
    M1.setTargetAbs(initial_steps);
    M3.setTargetAbs(initial_steps);
    step_controller.move(M1, M3);

    digitalWrite(Enable, HIGH); // Remove power from the motor to decrease heat  
}

void x_axis()
{
    digitalWrite(Enable, LOW); // Enable the motor again

    // Move y axis
    M2.setTargetAbs(initial_steps-steps);
    M4.setTargetAbs(initial_steps-steps);
    step_controller.move(M2, M4);

    digitalWrite(Enable, HIGH); // Remove power from the motor to decrease heat

    //delay(t);

    digitalWrite(Enable, LOW); // Enable the motor again

    // Com back to the origin
    M2.setTargetAbs(initial_steps);
    M4.setTargetAbs(initial_steps);
    step_controller.move(M2, M4);

    digitalWrite(Enable, HIGH); // Remove power from the motor to decrease heat  
}

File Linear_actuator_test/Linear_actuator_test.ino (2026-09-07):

#include "TeensyStep.h"
#include <Encoder.h>
#include <Wire.h>
#include <Adafruit_GFX.h>
#include <Adafruit_SSD1306.h>
#include <Bounce.h>

Encoder knob(11, 12);
const int encoder_SW = 13;
Bounce pushbutton = Bounce(encoder_SW, 50);  // 10 ms debounce
bool state = 0;

const int Enable = 2;
const int Enable_2 = 5;

Stepper My(6, 7);       // (STEP pin, DIR pin)  // The stepper class encapsulates the physical properties of a stepper motor like pin numbers of the STEP and DIR signals, speed and acceleration of the motor.
Stepper Mx(3, 4);
 
StepControl step_controller;    // The StepControl class is used to synchronously move up to 10 motors to their target positions.

float x;
float y;
const float Y0 = 67;
const float X0 = 15;
byte Xmax = 5;
byte Ymax = 3;
const float delta = 18.9;

bool dirx = true;
bool diry = true;
float f;
float t;

#define SCREEN_WIDTH 128 // OLED display width, in pixels
#define SCREEN_HEIGHT 64 // OLED display height, in pixels

// Declaration for an SSD1306 display connected to I2C (SDA, SCL pins)
#define OLED_RESET     -1 // Reset pin # (or -1 if sharing Arduino reset pin)

Adafruit_SSD1306 display(SCREEN_WIDTH, SCREEN_HEIGHT, &Wire, OLED_RESET);

const int MS1 = 8;
const int MS2 = 9;
const int MS3 = 10;

const int SWx = 14;
const int SWy = 15;

float um_per_step = 1.25; //400 steps/second
int steps = 0;
int steps_rel;

void setup()
{
  pinMode(MS1, OUTPUT);    // set the MS1, MS2, MS3 and Enable as an outputs
  pinMode(MS2, OUTPUT);
  pinMode(MS3, OUTPUT);
  
  pinMode(Enable, OUTPUT);
  pinMode(Enable_2, OUTPUT);


  digitalWrite(MS1, HIGH); 
  digitalWrite(MS2, LOW); 
  digitalWrite(MS3, LOW);
  
  digitalWrite(Enable, LOW); // set the enables to LOW
  digitalWrite(Enable_2, LOW); 


  pinMode(SWx, INPUT_PULLUP);
  pinMode(SWy, INPUT_PULLUP);
  
  // Set the motor max acceleration
  My.setMaxSpeed(10000)       // steps/s
      .setAcceleration(20000)   // stp/s^2
      .setInverseRotation(true);

  Mx.setMaxSpeed(10000)       // steps/s
      .setAcceleration(20000)   // stp/s^2
      .setInverseRotation(true);
      
  pinMode(encoder_SW, INPUT_PULLUP);
     
  Serial.begin(115200);
  
  display.begin(SSD1306_SWITCHCAPVCC, 0x3C);
  delay(1000); 
  display.clearDisplay();

  OLED_display();
  
  delay(2000); 
  
    // Homing routine

//  while (digitalRead(SWx) == HIGH)      
//  {
//    TurnClockwise_M1 (1000);
//    Serial.println(digitalRead(SWx));
//  }
//  while (digitalRead(SWy) == HIGH)      
//  {
//    TurnClockwise_M2 (100);
//    Serial.println(digitalRead(SWy));
//  }
}

void loop() 
{
    OLED_display();
    //read_pushbutton();
    //steps = knob.read()/2;
    steps = steps - 100;
    //Serial.println(steps); 
    Mx.setTargetAbs(steps);
    step_controller.move(Mx); 
    delay(3000); 

    
//    if (pushbutton.update()) 
//    {
//      if (pushbutton.fallingEdge()) 
//      {
//        knob.write(0);
//      }
//    } 
   
       
//       delay(t*1000);
//       Mx.setTargetAbs(0);
//       step_controller.move(Mx);
//       delay(t*1000);
  
}

// Function to get the steps from the mm
int mm_to_step (float mm)
{
  int steps;
  steps = mm*1600;// 1600 steps per mm
  return steps;
}

// Function to get the mm from the steps
float step_to_mm (int steps)
{
  float mm;
  mm = steps*0.000625; // 6.25 e-4 mm per step
  return mm;
}

//Function to rotate the left motor CW
void TurnClockwise_M1 (int pd)
{
   digitalWrite(4,1);
   digitalWrite(3,HIGH);
   digitalWrite(3,LOW);
   delayMicroseconds(pd);
}

//Function to rotate the right motor CW
void TurnClockwise_M2 (int pd)
{
   digitalWrite(7,1);
   digitalWrite(6,HIGH);
   digitalWrite(6,LOW);
   delayMicroseconds(pd);
}

void read_pushbutton()
{
    if (pushbutton.update()) 
    {
      if (pushbutton.fallingEdge()) 
      {
        state = !state;
      }
    } 
}

void OLED_display()
{   
    display.clearDisplay();
    display.setTextColor(WHITE);        // Draw white text
    display.setCursor(0, 0);
    display.setTextSize(1);
    display.println(F("Test"));
    display.println();
    display.print(F("Distance:"));
    display.print(-1*steps*um_per_step);
    display.println(F(" um"));
    display.display(); 
}

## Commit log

2022-07-08 Actuator V2
    [Accuracy actuator 8DOF cell stretcher.xlsx, Base.0012.ipt, Base.0027.ipt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]
2022-07-14 Mechanical V2
    [Base.dwg, Cart.0013.ipt, Cart.0014.ipt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]
2022-09-01 Electronics schematics
    [Accuracy actuator 8DOF cell stretcher.xlsx, Base.0027.ipt, Base.0031.ipt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]
2022-09-12 x4 mould
    [BOM_Cell stretcher control board_2022-09-07.csv, PDMS stretcher mould A (x4).ipt, PDMS stretcher mould A (x4).stl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]
2022-09-30 Firmware 4 DOF modes
    [BOM_Cell stretcher control board_2022-09-07.csv, PDMS stretcher mould A (x4).stl, PDMS stretcher mould A.ipt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]
2022-11-08 Step file assembly
    [Base.0031.ipt, Base.0032.ipt, Base.ipt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]
2026-09-07 V2 modifications
    [Accuracy actuator 8DOF cell stretcher.xlsx, BSP10-25 bottom.iam, BSP10-25 top.iam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]
